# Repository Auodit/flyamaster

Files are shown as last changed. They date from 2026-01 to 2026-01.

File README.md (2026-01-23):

# 🚁 FLYAMASTER 飞控项目

> ⚠️ **版权警告 / COPYRIGHT WARNING** ⚠️
>
> **本项目受版权保护，严格保留所有权利！**
>
> 🚫 **禁止** 未经授权的复制、修改、分发、商用
> 🚫 **禁止** Fork、Clone、Download 本仓库
> 🚫 **禁止** 转载、引用本项目任何内容
>
> 违者将依法追究法律责任！详见 [LICENSE](LICENSE)
>
> ---
>
> **This project is protected by copyright. All rights strictly reserved!**
>
> 🚫 **PROHIBITED**: Unauthorized copying, modification, distribution, commercial use
> 🚫 **PROHIBITED**: Fork, Clone, Download this repository
> 🚫 **PROHIBITED**: Repost or cite any content from this project
>
> Violators will be prosecuted! See [LICENSE](LICENSE)

---

**项目名称**: FLYAMASTER - F405 Mini 高性能穿越机飞控
**版本**: v2.4.0
**最后更新**: 2026-01-23
**状态**: 🟢 开发中 (软件完成，硬件设计完成，等待验证)
**作者**: LI
**助手**: Doro *(Desktop Pet / 桌面宠物)*

---

## 📖 项目简介

FLYAMASTER 是一款基于 **STM32F405RGT6** 的高性能、开源、易扩展的四轴飞行控制器。

### 🌟 项目由来

> *"每个飞手心中都有一个造飞控的梦。"*

这个项目源于我对无人机的热爱。从第一次看到穿越机在空中翻滚、俯冲的那一刻起，我就被这种自由飞翔的感觉深深吸引。作为一名嵌入式开发者，我不满足于仅仅使用现成的飞控，而是想要**从零开始**，亲手打造一款属于自己的飞行控制器。

这不仅仅是一个技术项目，更是一段探索之旅——从最初的 Mahony 姿态解算调试，到 PID 参数的反复调优；从 DMA 通道冲突的抓狂，到最终看到四轴稳稳悬停的那一刻的成就感。每一行代码、每一条 PCB 走线，都凝聚着对飞行的热爱和对技术的追求。

**FLYAMASTER** = **FLY** (飞行) + **A** (一个) + **MASTER** (大师) —— 愿每一位使用者都能成为飞行大师！

### 🎯 多固件支持

本硬件设计兼容多种主流开源飞控固件：

| 固件 | 适用场景 | 支持状态 |
|---|---|---|
| **INAV** | 固定翼 / 长航时无人机 / GPS 导航 | ✅ 完全兼容 |
| **Betaflight** | 穿越机 / 竞速无人机 / 花飞 | ✅ 完全兼容 |
| **ArduPilot** | 专业航拍 / 测绘 / 自主任务 | ✅ 完全兼容 |
| **FLYAMASTER (自研)** | 学习研究 / 定制开发 | ✅ 原生支持 |

> 💡 **提示**: 硬件引脚分配遵循 Betaflight 标准，可直接使用 Betaflight Configurator 进行配置。
> 对于 INAV 和 ArduPilot，需要创建对应的 Target 定义文件。

### 核心特性

- **高性能 MCU**: STM32F405RGT6 (168MHz, 1MB Flash, 192KB RAM)
- **多固件兼容**: 支持 INAV / Betaflight / ArduPilot / 自研固件
- **宽电压输入**: 支持 **2S-9S 电池** (4.5V-40V)，兼容各类电调
- **板载 OSD**: AT7456E 视频叠加芯片，实时显示飞行数据
- **实时操作系统**: FreeRTOS CMSIS_V2 (自研固件)
- **姿态解算**: Mahony 互补滤波 (500Hz)
- **控制算法**: 串级 PID (角度环 + 角速度环)
- **传感器融合**: IMU + 气压计 + 磁力计 + GPS + 光流
- **遥控接收**: ELRS/CRSF 协议 (420kbps, 双向遥测)
- **黑匣子**: W25Q128 Flash 日志记录 (16MB)
- **状态指示**: 7 颗专业级 LED 飞行仪表盘
- **USB 反灌保护**: 肖特基二极管隔离，安全可靠

### 设计哲学

1. **控制回路隔离**: 姿态解算与 PID 控制拥有最高优先级
2. **DMA 满载策略**: 所有高吞吐量接口强制开启 DMA
3. **资源冲突零容忍**: 针对 F405 的 DMA 通道冲突采用硬件重映射方案

---

## 🧠 核心算法原理

### 姿态解算 - Mahony 互补滤波

飞控的"大脑"是姿态解算算法。我们采用 **Mahony 互补滤波器**，它巧妙地融合了陀螺仪和加速度计的数据：

```
                    ┌─────────────────────────────────────────┐
                    │         Mahony 互补滤波器               │
                    └─────────────────────────────────────────┘
                    
    陀螺仪 (高频响应)                      加速度计 (低频稳定)
         │                                      │
         ▼                                      ▼
    ┌─────────┐                           ┌─────────┐
    │ 角速度  │                           │ 重力向量│
    │ ω       │                           │ a       │
    └────┬────┘                           └────┬────┘
         │                                      │
         │    ┌──────────────────────────┐     │
         └───►│  四元数微分方程积分       │◄────┘
              │  q̇ = ½ q ⊗ ω_corrected   │
              └───────────┬──────────────┘
                          │
                          ▼
                    ┌─────────┐
                    │ 四元数 q │ ──► Roll, Pitch, Yaw
                    └─────────┘
```

**核心公式**:
- 误差估计: `e = a × v` (加速度计测量值与估计重力方向的叉积)
- PI 校正: `ω_corrected = ω_gyro + Kp·e + Ki·∫e·dt`
- 四元数更新: `q += ½·q⊗ω·dt`

### 串级 PID 控制

采用**角度环 + 角速度环**的串级结构，外环输出作为内环的设定值：

```
    目标角度 ──┬──► [角度环 PID] ──► 目标角速度 ──┬──► [角速度环 PID] ──► 电机输出
               │                                  │
    当前角度 ──┘                    当前角速度 ──┘
```

**为什么用串级？**
- 外环 (角度环): 响应慢但稳定，负责"往哪飞"
- 内环 (角速度环): 响应快，负责"怎么飞"
- 两环配合，既稳定又灵敏

### 电机混控 - Airmode 算法

X 型机架的混控公式：
```
M1 (右前) = Throttle - Roll - Pitch - Yaw
M2 (左后) = Throttle + Roll + Pitch - Yaw
M3 (左前) = Throttle + Roll - Pitch + Yaw
M4 (右后) = Throttle - Roll + Pitch + Yaw
```

**Airmode 的精髓**: 当电机输出超限时，整体平移油门中心，保证姿态控制差分不变——"姿态优先，油门让步"。

---

## ⚡ 电路设计亮点

### 宽电压电源架构 (2S-9S)

```
    电池 (4.5-40V) ──► SY8303 DCDC ──► 5V/3A ──► RT9193 LDO ──► 3.3V/500mA
         │                  │                         │
         │                  ├──► USB 5V (带反灌保护)   ├──► MCU
         │                  ├──► 蜂鸣器               ├──► 传感器
         │                  └──► 外设接口             └──► Flash/OSD
         │
         ├──► 电机 (直接电池供电)
         └──► ADC 电压检测 (1:11 分压)
```

**为什么选 SY8303？**
- 输入范围 4.5-40V，覆盖 2S-9S 电池
- 效率高达 95%，发热小
- SOT-23-6 封装，体积小巧
- 价格仅 ¥0.8，性价比极高

### USB 反灌保护

**问题**: 电池供电时，5V 会通过 USB 反灌到电脑，导致 MCU 误判 USB 已连接。

**解决方案**: 肖特基二极管 (SS14) 隔离 + PB9 检测引脚

```
    USB VBUS ──┬──[SS14 二极管]──► +5V_USB
               │
               └──[10kΩ]──► PB9 (USB_DETECT, Pull-down)
```

### 7 颗 LED 专业飞行仪表盘

| 分组 | LED | 颜色 | 功能 |
|:---|:---|:---|:---|
| 核心系统 | LED_SYS | 蓝 | 系统心跳 (闪烁=待机, 常亮=已解锁) |
| 核心系统 | LED_ERR | 红 | 警告/错误 (快闪=传感器故障) |
| 导航链路 | LED_GPS | 绿 | GPS 状态 (闪烁=搜星, 常亮=3D Fix) |
| 导航链路 | LED_RX | 黄 | 遥控信号 (常亮=正常, 灭=Failsafe) |
| 飞行任务 | LED_MODE | 白 | 飞行模式指示 |
| 飞行任务 | LED_LOG | 橙 | 黑匣子记录状态 |
| 飞行任务 | LED_VTX | 青 | 图传状态 |

---

## 🔧 问题发现与解决

开发过程中遇到了不少"坑"，这里记录一些典型问题和解决方案：

### 问题 1: DMA 通道冲突

**现象**: WS2812 RGB 灯和 SBUS 接收机同时工作时，数据错乱。

**原因**: STM32F4 的 DMA 通道是硬件绑定的，TIM3_CH4 和 UART4_RX 共用 DMA1_Stream2。

**解决**: 将 WS2812 从 TIM3_CH4 (PB1) 迁移到 TIM1_CH1 (PA8)，使用 DMA2 通道，彻底隔离。

### 问题 2: I2C 总线竞争

**现象**: 多任务环境下，MPU6050 和 SPL06 偶发读取失败。

**原因**: 两个任务同时访问 I2C1 总线，导致冲突。

**解决**: 引入 FreeRTOS 互斥锁 (`i2c1MutexHandle`)，所有 I2C 操作前加锁，操作后解锁。

### 问题 3: Failsafe 油门被覆盖 (严重!)

**现象**: 失控保护触发后，飞机不下降反而继续按遥控器油门飞行。

**原因**: 代码中先设置 `throttle = FAILSAFE_DESCENT_THROTTLE`，后又被 `throttle = SBUS_GetThrottle()` 覆盖。

**解决**: 在读取遥控器油门前检查 Failsafe 状态，Failsafe 期间跳过遥控器输入。

### 问题 4: 偏航角漂移

**现象**: 飞机静止时，Yaw 角缓慢漂移。

**原因**: 仅使用 6 轴 IMU (加速度计+陀螺仪)，无法校正偏航。

**解决**: 集成 QMC5883L 磁力计，升级为 9 轴 AHRS，利用地磁场校正偏航。

### 问题 5: 高频 printf 导致控制抖动

**现象**: 在 500Hz 的 IMU 任务中加 printf 调试，飞机开始抖动。

**原因**: printf 是阻塞式的，每次调用耗时 1-2ms，严重影响控制回路。

**解决**: 开发 RingBuffer 异步日志系统，`Log_Printf()` 仅需 <10us，数据通过 DMA 后台发送。

---

## 🛠️ 技术栈

| 类别 | 技术选型 | 说明 |
|---|---|---|
| **MCU** | STM32F405RGT6 | ARM Cortex-M4F @ 168MHz |
| **RTOS** | FreeRTOS | CMSIS_V2 接口 |
| **IDE** | Keil MDK-ARM | ARM Compiler 6 |
| **配置工具** | STM32CubeMX | HAL 库生成 |
| **EDA** | KiCad 9.0 | PCB 设计 |
| **调试** | 匿名上位机 V7 | 实时数据可视化 |

---

## 📐 硬件设计

### PCB 渲染图

| 正面 (Top) | 反面 (Bottom) |
|:---:|:---:|
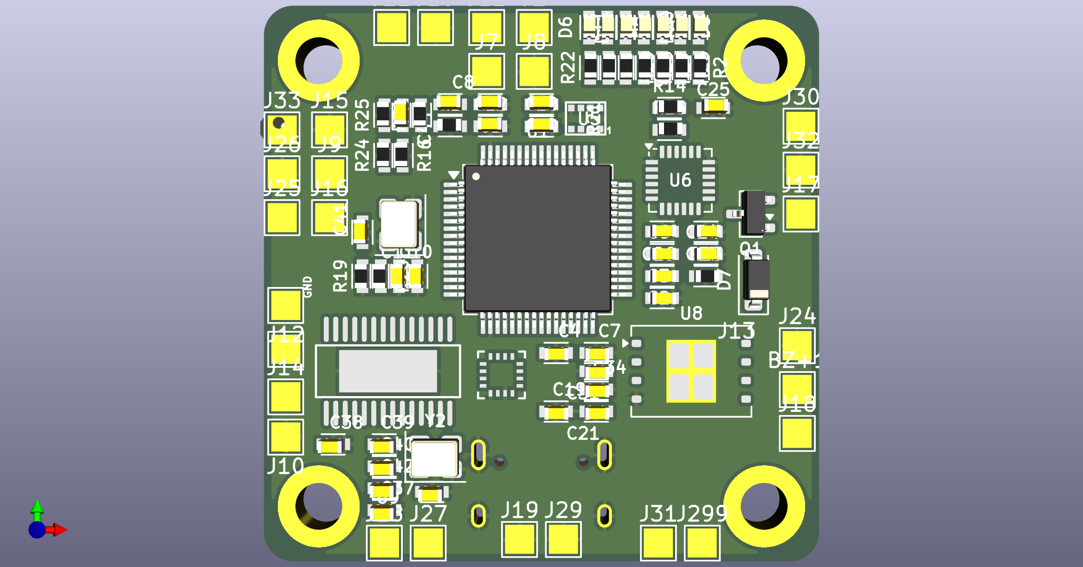
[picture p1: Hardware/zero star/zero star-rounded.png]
PCB 正面
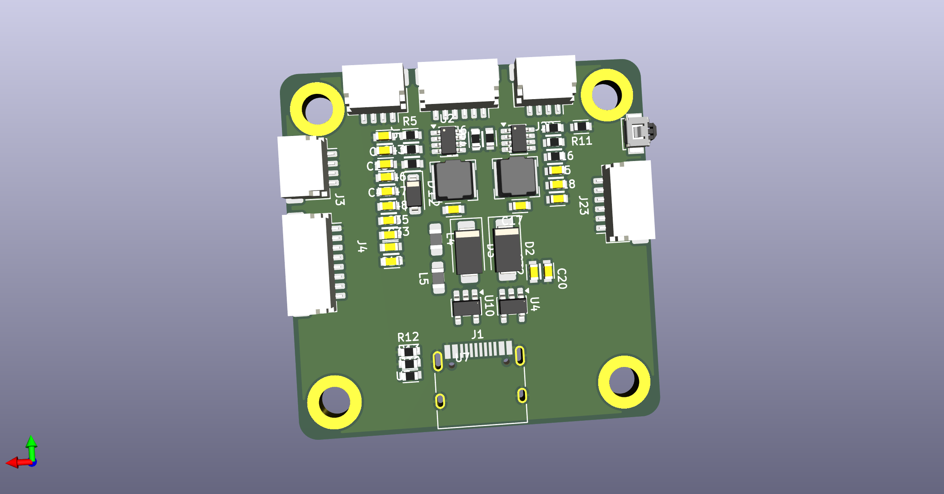
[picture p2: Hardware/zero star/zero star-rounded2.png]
PCB 反面
|  |  |

### 原理图

📄 **原理图 PDF**: [Hardware/zero star/zero star.pdf](Hardware/zero%20star/zero%20star.pdf)

### 主要芯片

| 芯片 | 功能 | 接口 |
|---|---|---|
| STM32F405RGT6 | 主控 MCU | - |
| MPU6050 | 6轴 IMU | I2C1 (0x68) |
| SPL06-001 | 气压计 | I2C1 (0x76) |
| QMC5883L | 磁力计 | I2C1 (0x0D) |
| W25Q128 | 16MB Flash | SPI1 |
| AT7456E | OSD 视频叠加 | SPI1 |
| SY8303 | DCDC 5V/3A (2S-9S 输入) | - |
| RT9193-33 | LDO 3.3V/500mA | - |

### 接口定义

| 接口 | 引脚 | 功能 | 波特率 |
|---|---|---|---|
| J1 | USB-C | 固件升级/调参 | CDC |
| J2 | PA2/PA3 | GPS 模块 | 115200 |
| J3 | PA9/PA10 | K210 上位机 | 921600 |
| J4 | PC6-PC9 | 4-in-1 ESC | PWM 400Hz |
| J5 | PC12/PD2 | 光流模块 | 115200 |
| J6 | PC10/PC11 | VTX SmartAudio | 115200  |
| J22 | PB10/PB11 | ELRS 接收机 | 420000 (CRSF) |

---

## 📚 文档索引

| 编号 | 文档名称 | 说明 | 链接 |
|---|---|---|---|
| 00 | README.md | 项目总览与索引 (本文档) | - |
| 01 | 01_definitions.md | 命名规范与接口定义 | [查看](plans/01_definitions.md) |
| 02 | 02_project_roadmap.md | 项目路线图与待办事项 | [查看](plans/02_project_roadmap.md) |
| 03 | 03_issue_tracker.md | 问题追踪日志 (Bug/Risk) | [查看](plans/03_issue_tracker.md) |
| 04 | 04_algo_design.md | 算法设计与优化记录 | [查看](plans/04_algo_design.md) |
| 05 | 05_changelog.md | 版本更新日志 | [查看](plans/05_changelog.md) |
| 06 | 06_operation_guide.md | 操作指南与环境搭建 | [查看](plans/06_operation_guide.md) |
| 07 | 07_research_and_ideas.md | 调研分析与创意池 | [查看](plans/07_research_and_ideas.md) |
| 08 | 08_hardware_design.md | 硬件架构与 PCB 设计 | [查看](plans/08_hardware_design.md) |

---

## 🚀 快速开始

### 1. 环境准备

```bash
# 必需软件
- Keil MDK-ARM v5.38+
- STM32CubeMX v6.10+
- ST-Link 驱动
```

### 2. 编译项目

1. 打开 `FLYAMASTER/MDK-ARM/FLYAMASTER.uvprojx`
2. 点击 `Build` (F7) 编译
3. 点击 `Download` (F8) 烧录

### 3. 调试连接

- **SWD 接口**: PA13 (SWDIO), PA14 (SWCLK)
- **USB 虚拟串口**: PA11/PA12 (CDC)
- **匿名上位机**: USART1 (PA9/PA10) @ 921600 baud

---

## 📁 目录结构

```
FLYAMASTER/
├── 3D/                      # 3D 模型文件
├── FLYAMASTER/              # 固件源代码
│   ├── Core/
│   │   ├── Inc/             # 头文件
│   │   │   ├── mpu6050.h    # IMU 驱动
│   │   │   ├── mahony.h     # 姿态解算
│   │   │   ├── pid.h        # PID 控制器
│   │   │   ├── motor.h      # 电机混控
│   │   │   ├── sbus.h       # CRSF 接收
│   │   │   ├── gps.h        # GPS 解析
│   │   │   ├── at7456e.h    # OSD 驱动
│   │   │   └── ...
│   │   └── Src/             # 源文件
│   │       ├── freertos.c   # RTOS 任务
│   │       ├── mpu6050.c    # IMU 驱动实现
│   │       ├── mahony.c     # Mahony 滤波
│   │       ├── pid.c        # PID 算法
│   │       ├── motor.c      # 电机控制
│   │       └── ...
│   └── MDK-ARM/             # Keil 工程
│       ├── FLYAMASTER.uvprojx
│       └── ...
├── Hardware/                # 硬件设计
│   └── zero star/           # KiCad 工程
│       ├── zero star.kicad_sch    # 原理图
│       ├── zero star.kicad_pcb    # PCB
│       └── zero star.pdf          # 原理图 PDF
├── plans/                   # 项目文档
│   ├── README.md            # 文档索引
│   ├── 01_definitions.md    # 接口定义
│   ├── 02_project_roadmap.md # 路线图
│   ├── 03_issue_tracker.md  # 问题追踪
│   ├── 04_algo_design.md    # 算法设计
│   ├── 05_changelog.md      # 更新日志
│   ├── 06_operation_guide.md # 操作指南
│   ├── 07_research_and_ideas.md # 调研分析
│   ├── 08_hardware_design.md # 硬件设计
│   └── archive/             # 废弃文档归档
├── .gitignore               # Git 忽略规则
└── LICENSE                  # 版权声明
```

---

## 🎯 项目状态

### ✅ 已完成

- [x] 硬件驱动 (IMU, PWM, CRSF, GPS, OSD)
- [x] 姿态解算 (Mahony 互补滤波)
- [x] 姿态控制 (串级 PID)
- [x] 定高控制 (气压计 PID)
- [x] GPS 定点 (位置环 PID)
- [x] OSD 显示 (AT7456E)
- [x] 匿名上位机协议 (V7)
- [x] 硬件原理图设计 (KiCad)
- [x] 7 颗 LED 状态指示系统
- [x] USB 插入检测 (反灌保护)

### 🚧 进行中

- [ ] PCB 布局优化
- [ ] 打样验证

### 📋 计划中

- [ ] EKF 状态估计 (可选)
- [ ] 航点飞行
- [ ] 自动返航 (RTH)

---

## 👥 贡献者

- **LI** - 项目作者 & 核心开发者
- **Doro** *(Desktop Pet / 桌面宠物)* - AI 助手 & 文档撰写

---

## ⚖️ 版权声明

```
================================================================================
                    FLYAMASTER 飞控项目 - 版权声明
================================================================================

版权所有 (C) 2026 FLYAMASTER 项目组
Copyright (C) 2026 FLYAMASTER Project Team

                       严格保留所有权利
                  ALL RIGHTS STRICTLY RESERVED

未经版权所有者明确书面授权，严禁：
1. 复制、下载、存储本项目的任何部分
2. 修改、改编、翻译本项目的任何内容
3. 分发、传播、共享本项目的任何文件
4. 将本项目用于任何商业目的
5. 基于本项目创建衍生作品
6. 对本项目进行逆向工程
7. 在任何平台转载、引用本项目内容

任何未经授权的使用将被视为侵权，版权所有者保留追究法律责任的权利。

详见 LICENSE 文件
================================================================================
```

---

## 🙏 致谢

感谢开源社区的前辈们，特别是：
- **Betaflight** / **INAV** / **ArduPilot** 项目，提供了宝贵的参考
- **Mahony** 和 **Madgwick** 的姿态解算算法论文
- **立创开源硬件平台**，提供了电源方案参考
- 所有在 GitHub Issues 中提供反馈的朋友们

---

**文档版本**: v2.4.0
**最后更新**: 2026-01-23
**作者**: LI | **助手**: Doro

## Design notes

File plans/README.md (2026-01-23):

# 🚁 FLYAMASTER 飞控项目

> ⚠️ **版权警告 / COPYRIGHT WARNING** ⚠️
>
> **本项目受版权保护，严格保留所有权利！**
>
> 🚫 **禁止** 未经授权的复制、修改、分发、商用
> 🚫 **禁止** Fork、Clone、Download 本仓库
> 🚫 **禁止** 转载、引用本项目任何内容
>
> 违者将依法追究法律责任！详见 [LICENSE](../LICENSE)
>
> ---
>
> **This project is protected by copyright. All rights strictly reserved!**
>
> 🚫 **PROHIBITED**: Unauthorized copying, modification, distribution, commercial use
> 🚫 **PROHIBITED**: Fork, Clone, Download this repository
> 🚫 **PROHIBITED**: Repost or cite any content from this project
>
> Violators will be prosecuted! See [LICENSE](../LICENSE)

---

**项目名称**: FLYAMASTER - F405 Mini 高性能穿越机飞控
**版本**: v2.4.0
**最后更新**: 2026-01-23
**状态**: 🟢 开发中 (软件完成，硬件设计完成，等待验证)

---

## 📖 项目简介

FLYAMASTER 是一款基于 **STM32F405RGT6** 的高性能、开源、易扩展的四轴飞行控制器。

### 核心特性

- **高性能 MCU**: STM32F405RGT6 (168MHz, 1MB Flash, 192KB RAM)
- **实时操作系统**: FreeRTOS CMSIS_V2
- **姿态解算**: Mahony 互补滤波 (500Hz)
- **控制算法**: 串级 PID (角度环 + 角速度环)
- **传感器融合**: IMU + 气压计 + 磁力计 + GPS + 光流
- **OSD 显示**: AT7456E 视频叠加
- **黑匣子**: W25Q128 Flash 日志记录

### 设计哲学

1. **控制回路隔离**: 姿态解算与 PID 控制拥有最高优先级
2. **DMA 满载策略**: 所有高吞吐量接口强制开启 DMA
3. **资源冲突零容忍**: 针对 F405 的 DMA 通道冲突采用硬件重映射方案

---

## 🛠️ 技术栈

| 类别 | 技术选型 | 说明 |
|---|---|---|
| **MCU** | STM32F405RGT6 | ARM Cortex-M4F @ 168MHz |
| **RTOS** | FreeRTOS | CMSIS_V2 接口 |
| **IDE** | Keil MDK-ARM | ARM Compiler 6 |
| **配置工具** | STM32CubeMX | HAL 库生成 |
| **EDA** | 立创 EDA / KiCad | PCB 设计 |
| **调试** | 匿名上位机 V7 | 实时数据可视化 |

---

## 📚 文档索引

| 编号 | 文档名称 | 说明 | 链接 |
|---|---|---|---|
| 00 | README.md | 项目总览与索引 (本文档) | - |
| 01 | 01_definitions.md | 命名规范与接口定义 | [查看](01_definitions.md) |
| 02 | 02_project_roadmap.md | 项目路线图与待办事项 | [查看](02_project_roadmap.md) |
| 03 | 03_issue_tracker.md | 问题追踪日志 (Bug/Risk) | [查看](03_issue_tracker.md) |
| 04 | 04_algo_design.md | 算法设计与优化记录 | [查看](04_algo_design.md) |
| 05 | 05_changelog.md | 版本更新日志 | [查看](05_changelog.md) |
| 06 | 06_operation_guide.md | 操作指南与环境搭建 | [查看](06_operation_guide.md) |
| 07 | 07_research_and_ideas.md | 调研分析与创意池 | [查看](07_research_and_ideas.md) |
| 08 | 08_hardware_design.md | 硬件架构与 PCB 设计 | [查看](08_hardware_design.md) |

---

## 🚀 快速开始

### 1. 环境准备

```bash
# 必需软件
- Keil MDK-ARM v5.38+
- STM32CubeMX v6.10+
- ST-Link 驱动
```

### 2. 编译项目

1. 打开 `MDK-ARM/FLYAMASTER.uvprojx`
2. 点击 `Build` (F7) 编译
3. 点击 `Download` (F8) 烧录

### 3. 调试连接

- **SWD 接口**: PA13 (SWDIO), PA14 (SWCLK)
- **USB 虚拟串口**: PA11/PA12 (CDC)
- **匿名上位机**: UART5 (PC12/PD2) @ 115200 baud

---

## 📁 目录结构

```
FLYAMASTER/
├── Core/
│   ├── Inc/                 # 头文件
│   │   ├── mpu6050.h        # IMU 驱动
│   │   ├── mahony.h         # 姿态解算
│   │   ├── pid.h            # PID 控制器
│   │   ├── motor.h          # 电机混控
│   │   ├── sbus.h           # 遥控器接收
│   │   ├── gps.h            # GPS 解析
│   │   ├── at7456e.h        # OSD 驱动
│   │   └── ...
│   └── Src/                 # 源文件
│       ├── freertos.c       # RTOS 任务
│       ├── mpu6050.c        # IMU 驱动实现
│       ├── mahony.c         # Mahony 滤波
│       ├── pid.c            # PID 算法
│       ├── motor.c          # 电机控制
│       └── ...
├── MDK-ARM/                 # Keil 工程
│   ├── FLYAMASTER.uvprojx   # 工程文件
│   └── ...
└── plans/                   # 项目文档
    ├── README.md            # 本文档
    ├── 01_definitions.md    # 接口定义
    ├── 02_project_roadmap.md # 路线图
    ├── 03_issue_tracker.md  # 问题追踪
    ├── 04_algo_design.md    # 算法设计
    ├── 05_changelog.md      # 更新日志
    ├── 06_operation_guide.md # 操作指南
    ├── 07_research_and_ideas.md # 调研分析
    ├── 08_hardware_design.md # 硬件设计
    └── archive/             # 废弃文档归档
```

---

## 🎯 项目状态

### ✅ 已完成

- [x] 硬件驱动 (IMU, PWM, SBUS, GPS, OSD)
- [x] 姿态解算 (Mahony 互补滤波)
- [x] 姿态控制 (串级 PID)
- [x] 定高控制 (气压计 PID)
- [x] GPS 定点 (位置环 PID)
- [x] OSD 显示 (AT7456E)
- [x] 匿名上位机协议 (V7)

### 🚧 进行中

- [ ] 硬件原理图设计
- [ ] PCB 布局
- [ ] 打样验证

### 📋 计划中

- [ ] EKF 状态估计 (可选)
- [ ] 航点飞行
- [ ] 自动返航 (RTH)

---

## 👥 贡献者

- **Q版 Doro** - 项目负责人
- **Kilo Code** - AI 辅助开发

---

## ⚖️ 版权声明

```
================================================================================
                    FLYAMASTER 飞控项目 - 版权声明
================================================================================

版权所有 (C) 2026 FLYAMASTER 项目组
Copyright (C) 2026 FLYAMASTER Project Team

                       严格保留所有权利
                  ALL RIGHTS STRICTLY RESERVED

未经版权所有者明确书面授权，严禁：
1. 复制、下载、存储本项目的任何部分
2. 修改、改编、翻译本项目的任何内容
3. 分发、传播、共享本项目的任何文件
4. 将本项目用于任何商业目的
5. 基于本项目创建衍生作品
6. 对本项目进行逆向工程
7. 在任何平台转载、引用本项目内容

任何未经授权的使用将被视为侵权，版权所有者保留追究法律责任的权利。

详见 LICENSE 文件
================================================================================
```

---

**文档版本**: v2.4.0
**最后更新**: 2026-01-23

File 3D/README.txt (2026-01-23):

Peon230 - Quadcopter by Tech2C on Thingiverse: https://www.thingiverse.com/thing:629338

Summary:
Designed for strength, function and light weight, build yourself this 230 size Quadcopter frame.  All parts printed at 0.2mm layer height and 3 perimeters.  -Top and Bottom frames, HDcam and FPVcam @ 30% infill x 1 of each-Arms @ 100% infill x 4-ArmSupport @ 100% infill x 2 http://youtu.be/-e-3kbXzwzkhttp://youtu.be/jaZK9bDb17Uhttp://youtu.be/BU2Z-EG56js  Suggested Setup:-Motor: RacerStar 1806 2280kv or Racerstar 2204 2300KV-ESC: Racerstar RS20Ax4 20A 4 in 1 (inbuilt PDB)-Prop: 10 Pairs GEPRC 5040 V2 5 Inch 3 Blade Propeller -Flight Controller: F3 Acro or F4 with Current Sensor-Battery: ZOP 3S 1100mah 65c or ZOP 4S 1100mah 65c-LiPo Battery Charger:iMAX B6 Digital RC Lipo Balance Charger12V 5A AC Power AdapterXT60 Connector to Banana Plug-Remote Control:FlySky FS-i6 orFrSky Taranis Transmitter and FrSky XM+ ReceiverHDcam mounting strap slots compatible with Mobius, RunCam and GoPro. -Optional extras if you need them:Lipo Battery Tie Down StrapXT60 Male Female Plug Connector 12AWG 10cm Power CableSilicone Anti-vibration Pad in for 22XX Series MotorNon-printed parts required:-12 x M3x10mm countersunk screws for Top/Bottom frame (Amazon affiliate link)-6 x M3x40mm Nylon Spacers for Top/Bottom frame (Amazon affiliate link)-8 x M3x12mm countersunk screws for Arms (Amazon affiliate link)-8 x M3 Nyloc nuts for Arms (Amazon affiliate link)-3 x Vibration Ball Dampeners for HDcamUpdatedBase and Top v1.1 - rear mounting spacers moved further back for better rear arm support.Added 22 size Motor ArmEnjoy this design? Consider supporting me on Patreon: https://www.patreon.com/Tech2C

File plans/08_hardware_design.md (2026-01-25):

# 🛠️ 硬件架构与PCB设计 (Hardware Design)

**版本**: v2.5.7 (STM32F405RGT6 - PCB Layout Final)
**最后更新**: 2026-01-25
**状态**: ✅ CubeMX 已生成

---

## 0. 硬件变更记录 (Hardware Revision Log)

| 版本 | 日期 | 变更内容 |
|:---|:---|:---|
| v2.0.0 | 2026-01-18 | 迁移至 STM32F405RGT6 (LQFP-64) |
| v2.2.0 | 2026-01-23 | 串口重新分配：USART3 用于 ELRS |
| v2.3.0 | 2026-01-23 | 新增 7 颗 LED |
| v2.4.0 | 2026-01-23 | 新增 USB 插入检测 (PB9) |
| v2.5.0 | 2026-01-24 | PCB 布局深度优化：按物理边沿重排引脚 |
| v2.5.2 | 2026-01-24 | 布局微调：顶部仅保留传感器，插座全部移至左/右/下侧 |
| v2.5.3 | 2026-01-24 | USART2/UART5 对调：UART5 用于 GPS，USART2 用于光流 |
| v2.5.4 | 2026-01-24 | 引脚调整：PC5 改为 USB_DETECT，电流检测移至 PC1 (ADC11) |
| v2.5.5 | 2026-01-24 | I2C1_SCL 重映射：PB6 → PB8 |
| v2.5.6 | 2026-01-24 | I2C1 完整重映射 (PB8/PB9)，USART1 重映射 (PB6/PB7) |
| **v2.5.7** | **2026-01-25** | **SPI 片选对调：PA4→OSD_CS，PC4→FLASH_CS** |

---

## 1. MCU 引脚分配表 (Pinout Map) - 按物理边沿排列

> **方向定义**: 以芯片丝印正向为准，Pin 1 为左上角。

### 1.1 顶部边沿 (Top Edge, Pins 49-64)
*布局目标: I2C 传感器 (PCB 顶部区域)*

| Pin | Label | Function | Net Name | Note |
|:---|:---|:---|:---|:---|
| PB9 | I2C1_SDA | I2C1 | I2C1_SDA | **传感器总线** (重映射) |
| PB8 | I2C1_SCL | I2C1 | I2C1_SCL | **传感器总线** (重映射) |
| BOOT0 | BOOT0 | System | BOOT0 | 启动模式选择 (背面开关) |
| PB7 | USART1_RX | USART1 | VTX_RX | **SmartAudio 图传** (重映射) |
| PB6 | USART1_TX | USART1 | VTX_TX | **SmartAudio 图传** (重映射) |
| PB5 | MPU_INT | GPIO_EXTI5 | MPU_INT | IMU 中断 |
| PB4 | GPIO_Output | GPIO_Output | - | 备用 |
| PB3 | GPIO_Output | GPIO_Output | - | 备用 |
| PD2 | UART5_RX | UART5 | **GPS_RX** | **GPS 模块** (引至左侧插座) |
| PC12 | UART5_TX | UART5 | **GPS_TX** | **GPS 模块** (引至左侧插座) |
| PC11 | UART4_RX | UART4 | LOG_RX | K210/调试日志 (引至左侧插座) |
| PC10 | UART4_TX | UART4 | LOG_TX | K210/调试日志 (引至左侧插座) |
| PA15 | - | - | - | 备用 |
| PA14 | SWCLK | SYS | SWCLK | SWD 调试接口 |

### 1.2 右侧边沿 (Right Edge, Pins 33-48)
*布局目标: USB, VTX, Motors, LEDs*

| Pin | Label | Function | Net Name | Note |
|:---|:---|:---|:---|:---|
| PA13 | SWDIO | SYS | SWDIO | SWD 调试接口 |
| PA12 | USB_DP | USB_OTG_FS | USB_DP | USB Type-C (背面) |
| PA11 | USB_DM | USB_OTG_FS | USB_DM | USB Type-C (背面) |
| PA10 | GPIO_Output | GPIO_Output | - | 备用 (原 USART1_RX) |
| PA9 | GPIO_Output | GPIO_Output | - | 备用 (原 USART1_TX) |
| PA8 | LED_RGB | TIM1_CH1 | LED_RGB | 4颗 WS2812 (位于PCB四角) |
| PC9 | MOTOR_4 | TIM8_CH4 | M4 | 电机 4 (CW) |
| PC8 | MOTOR_3 | TIM8_CH3 | M3 | 电机 3 (CCW) |
| PC7 | MOTOR_2 | TIM8_CH2 | M2 | 电机 2 (CCW) |
| PC6 | MOTOR_1 | TIM8_CH1 | M1 | 电机 1 (CW) |
| PB15 | LED_VTX | GPIO_Output | LED_VTX | 状态灯 4 (青色) - 图传 |
| PB14 | LED_LOG | GPIO_Output | LED_LOG | 状态灯 3 (橙色) - 日志 |
| PB13 | LED_MODE | GPIO_Output | LED_MODE | 状态灯 2 (白色) - 模式 |
| PB12 | LED_SYS | GPIO_Output | LED_SYS | 状态灯 1 (蓝色) - 系统 |

### 1.3 底部边沿 (Bottom Edge, Pins 17-32)
*布局目标: SPI (Flash/OSD), ELRS, 光流*

| Pin | Label | Function | Net Name | Note |
|:---|:---|:---|:---|:---|
| PB11 | USART3_RX | USART3 | ELRS_RX | **ELRS 接收机** (焊盘) |
| PB10 | USART3_TX | USART3 | ELRS_TX | **ELRS 接收机** (焊盘) |
| PB2 | GPIO_Output | GPIO_Output | - | 备用 (BOOT1) |
| PB1 | GPIO_Output | GPIO_Output | - | 备用 |
| PB0 | GPIO_Output | GPIO_Output | - | 备用 |
| PC5 | USB_DETECT | GPIO_Input | USB_DET | **USB 插入检测** |
| PC4 | FLASH_CS | GPIO_Output | FLASH_CS | **Flash 片选** (靠近 SPI) |
| PA7 | SPI1_MOSI | SPI1 | SPI1_MOSI | Flash + OSD |
| PA6 | SPI1_MISO | SPI1 | SPI1_MISO | Flash + OSD |
| PA5 | SPI1_SCK | SPI1 | SPI1_SCK | Flash + OSD |
| PA4 | OSD_CS | GPIO_Output | OSD_CS | **OSD 片选** |
| PA3 | USART2_RX | USART2 | **FLOW_RX** | **光流模块** (底部/左侧插座) |

### 1.4 左侧边沿 (Left Edge, Pins 1-16)
*布局目标: Power, Buzzer, 光流*

| Pin | Label | Function | Net Name | Note |
|:---|:---|:---|:---|:---|
| PA2 | USART2_TX | USART2 | **FLOW_TX** | **光流模块** (底部/左侧插座) |
| PA1 | - | - | - | 备用 |
| PA0 | Power_Key | GPIO_Input | POWER_KEY | 电源按键 (可选) |
| PC3 | - | - | - | 备用 |
| PC2 | BUZZER | GPIO_Output | BUZZER | 蜂鸣器 |
| PC1 | I_BAT | ADC1_IN11 | CURR_SENSE | **电流检测** |
| PC0 | V_BAT | ADC1_IN10 | VBAT_SENSE | 电压检测 |
| NRST | NRST | System | NRST | 复位 |
| PH1 | OSC_OUT | RCC | HSE_OUT | 8MHz 晶振 |
| PH0 | OSC_IN | RCC | HSE_IN | 8MHz 晶振 |

---

## 2. 串口分配汇总 (UART Assignment Summary)

| 串口 | 引脚 | 波特率 | 用途 | 接口类型 | 位置 |
|:---|:---|:---|:---|:---|:---|
| **USART1** | PB6/PB7 | 4800 | SmartAudio VTX | J6 插座 | 顶部 (重映射) |
| **USART2** | PA2/PA3 | 115200 | **光流模块** | J5 插座 | 底部/左侧 |
| **USART3** | PB10/PB11 | 420000 | ELRS (CRSF) | 焊盘 | 底部 |
| **UART4** | PC10/PC11 | 921600 | K210/日志 | J3 插座 | 顶部→左侧 |
| **UART5** | PC12/PD2 | 115200 | **GPS 模块** | J2 插座 | 顶部→左侧 |

---

## 3. 关键布局约束 (PCB Layout Constraints)

### 3.1 物理分区
*   **Top (上)**: **传感器专用区**。MPU6050, SPL06, QMC5883L 放置在 PCB 顶部中间，I2C 走线极短。**顶部边缘不放置任何插座**。
*   **Right (右)**: **接口区**。USB Type-C (背面), J6 (VTX), 电机焊盘。
*   **Bottom (下)**: **存储与 OSD 区**。Flash, AT7456E, ELRS 焊盘。SPI 走线紧凑。
*   **Left (左)**: **电源与外设区**。LDO, DCDC, ADC 检测。GPS (J2), 光流 (J5), 日志 (J3) 插座。

### 3.2 特殊走线要求
*   **USB (PA11/PA12)**: 差分走线，90Ω 阻抗控制，尽量短。
*   **OSD 视频线**: 模拟视频信号 (VIN/VOUT) 必须包地，远离 DCDC 电感和电机线。
*   **晶振 (PH0/PH1)**: 下方挖空，禁止走线，包地保护。
*   **电流检测 (PC5)**: 采样电阻出来的信号线需开尔文连接 (Kelvin Connection)。

---

## 4. LED 指示灯系统 (4 颗)

| 引脚 | 颜色 | 标签 | 功能定义 | 状态逻辑 (低电平亮) |
|:---|:---|:---|:---|:---|
| **PB12** | **蓝色** | **LED_SYS** | **系统状态** | **闪烁**: 待机正常 (心跳)<br>**常亮**: 已解锁 (Armed)<br>**灭**: 初始化中 |
| **PB13** | **白色** | **LED_MODE** | **飞行模式** | **灭**: 自稳/半自稳 (Angle/Horizon)<br>**亮**: 手动模式 (Acro)<br>**闪烁**: 返航/救援 (RTH/Rescue) |
| **PB14** | **绿色** | **LED_GPS** | **GPS 状态** | **灭**: 无 GPS 信号<br>**闪烁**: 搜星中<br>**常亮**: GPS 3D 锁定 (Ready) |
| **PB15** | **青色** | **LED_VTX** | **图传/警告** | **灭**: 正常<br>**亮**: 图传处于 PIT 模式 (低功率)<br>**快闪**: 电池低压/故障警告 |

---

## 5. DMA 通道分配

由于串口位置变更，DMA 通道需重新确认：

*   **USART1 (VTX)**: PB6/PB7 (重映射). DMA2_Stream7 (TX) / DMA2_Stream2 (RX). **OK**.
*   **USART2 (光流)**: PA2/PA3. DMA1_Stream6 (TX) / DMA1_Stream5 (RX). **OK**.
*   **USART3 (ELRS)**: PB10/PB11. DMA1_Stream3 (TX) / DMA1_Stream1 (RX). **OK**.
*   **UART4 (Log)**: PC10/PC11. DMA1_Stream4 (TX) / DMA1_Stream2 (RX). **OK**.
*   **UART5 (GPS)**: PC12/PD2. DMA1_Stream7 (TX) / DMA1_Stream0 (RX). **OK**.

---

## 6. 备用引脚汇总

| 引脚 | 位置 | 可用功能 | 建议用途 |
|:---|:---|:---|:---|
| PC13 | 左上 | GPIO (RTC 备份域) | 备用 LED 或使能信号 |
| PC14 | 左上 | GPIO (LSE) | 备用 (需禁用 LSE) |
| PC15 | 左上 | GPIO (LSE) | 备用 (需禁用 LSE) |
| PA0 | 左下 | GPIO/ADC | Power_Key 或备用 ADC |
| PA1 | 左下 | GPIO/ADC | 备用 ADC |
| PA9/PA10 | 右侧 | GPIO/USART1 | 备用 (原 USART1) |
| PA15 | 右上 | GPIO/TIM2_CH1 | 备用 PWM 或 GPIO |
| PB0/PB1/PB2 | 底部 | GPIO/ADC | 备用 |
| PB3/PB4 | 顶部 | GPIO/SPI3 | 备用 |
| PC3 | 左侧 | GPIO/ADC | 备用 |

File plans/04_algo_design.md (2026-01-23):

# 算法设计与优化记录

> 文档版本: 1.0.0  
> 更新日期: 2026-01-18  
> 项目: FLYAMASTER 四轴飞控

---

## 目录

1. [姿态解算算法 (Mahony Filter)](#1-姿态解算算法-mahony-filter)
2. [串级 PID 控制器](#2-串级-pid-控制器)
3. [电机混控算法](#3-电机混控算法)
4. [气压高度计算](#4-气压高度计算)
5. [快速数学函数](#5-快速数学函数)
6. [滤波算法](#6-滤波算法)

---

## 1. 姿态解算算法 (Mahony Filter)

### 1.1 算法概述

Mahony 互补滤波器是一种基于四元数的姿态估计算法，通过融合陀螺仪和加速度计数据，实现高精度、低延迟的姿态解算。

**文件位置**: [`mahony.c`](../FLYAMASTER/Core/Src/mahony.c), [`mahony.h`](../FLYAMASTER/Core/Inc/mahony.h)

### 1.2 数学原理

#### 四元数表示

姿态使用四元数 $\mathbf{q} = [q_0, q_1, q_2, q_3]^T$ 表示，其中：
- $q_0$ 为标量部分 (w)
- $q_1, q_2, q_3$ 为向量部分 (x, y, z)

约束条件：$\|\mathbf{q}\| = 1$

#### 四元数微分方程

$$\dot{\mathbf{q}} = \frac{1}{2} \mathbf{q} \otimes \boldsymbol{\omega}$$

其中 $\boldsymbol{\omega} = [0, \omega_x, \omega_y, \omega_z]^T$ 为角速度四元数。

展开形式：
$$\begin{bmatrix} \dot{q}_0 \\ \dot{q}_1 \\ \dot{q}_2 \\ \dot{q}_3 \end{bmatrix} = \frac{1}{2} \begin{bmatrix} -q_1 & -q_2 & -q_3 \\ q_0 & -q_3 & q_2 \\ q_3 & q_0 & -q_1 \\ -q_2 & q_1 & q_0 \end{bmatrix} \begin{bmatrix} \omega_x \\ \omega_y \\ \omega_z \end{bmatrix}$$

#### 误差估计

利用加速度计测量的重力方向与四元数估计的重力方向之间的误差：

估计的重力方向（从四元数计算）：
$$\mathbf{v} = \begin{bmatrix} 2(q_1 q_3 - q_0 q_2) \\ 2(q_0 q_1 + q_2 q_3) \\ q_0^2 - q_1^2 - q_2^2 + q_3^2 \end{bmatrix}$$

误差向量（叉积）：
$$\mathbf{e} = \mathbf{a} \times \mathbf{v}$$

其中 $\mathbf{a}$ 为归一化的加速度计测量值。

#### PI 校正

使用 PI 控制器校正陀螺仪漂移：

$$\boldsymbol{\omega}_{corrected} = \boldsymbol{\omega}_{gyro} + K_p \mathbf{e} + K_i \int \mathbf{e} \, dt$$

### 1.3 伪代码

```
function Mahony_UpdateIMU(gx, gy, gz, ax, ay, az):
    dt = 1 / sample_freq
    
    // 归一化加速度计
    norm = sqrt(ax² + ay² + az²)
    ax, ay, az = ax/norm, ay/norm, az/norm
    
    // 估计重力方向
    vx = q1*q3 - q0*q2
    vy = q0*q1 + q2*q3
    vz = q0² - 0.5 + q3²
    
    // 计算误差 (叉积)
    ex = ay*vz - az*vy
    ey = az*vx - ax*vz
    ez = ax*vy - ay*vx
    
    // 积分误差
    integralFBx += Ki * ex * dt
    integralFBy += Ki * ey * dt
    integralFBz += Ki * ez * dt
    
    // 校正角速度
    gx += Kp * ex + integralFBx
    gy += Kp * ey + integralFBy
    gz += Kp * ez + integralFBz
    
    // 积分四元数
    gx *= 0.5 * dt
    gy *= 0.5 * dt
    gz *= 0.5 * dt
    
    q0 += -q1*gx - q2*gy - q3*gz
    q1 += q0*gx + q2*gz - q3*gy
    q2 += q0*gy - q1*gz + q3*gx
    q3 += q0*gz + q1*gy - q2*gx
    
    // 归一化四元数
    normalize(q0, q1, q2, q3)
```

### 1.4 四元数转欧拉角

$$\phi = \arctan2(2(q_0 q_1 + q_2 q_3), 1 - 2(q_1^2 + q_2^2))$$

$$\theta = \arcsin(2(q_0 q_2 - q_3 q_1))$$

$$\psi = \arctan2(2(q_0 q_3 + q_1 q_2), 1 - 2(q_2^2 + q_3^2))$$

### 1.5 参数配置

| 参数 | 默认值 | 说明 |
|---|---|---|
| `MAHONY_DEFAULT_KP` | 2.0 | 比例增益，越大收敛越快但可能振荡 |
| `MAHONY_DEFAULT_KI` | 0.005 | 积分增益，消除稳态误差 |
| `MAHONY_SAMPLE_FREQ` | 500 Hz | 采样频率 |

---

## 2. 串级 PID 控制器

### 2.1 算法概述

采用串级 PID 控制结构：
- **外环 (角度环)**: 目标角度 → 目标角速度
- **内环 (角速度环)**: 目标角速度 → 电机输出

**文件位置**: [`pid.c`](../FLYAMASTER/Core/Src/pid.c), [`pid.h`](../FLYAMASTER/Core/Inc/pid.h)

### 2.2 数学原理

#### 标准 PID 公式

$$u(t) = K_p e(t) + K_i \int_0^t e(\tau) d\tau + K_d \frac{de(t)}{dt}$$

离散化形式：
$$u[k] = K_p e[k] + K_i \sum_{i=0}^{k} e[i] \Delta t + K_d \frac{e[k] - e[k-1]}{\Delta t}$$

#### 串级控制结构

```
目标角度 ──┬──► [角度环 PID] ──► 目标角速度 ──┬──► [角速度环 PID] ──► 电机输出
           │                                  │
当前角度 ──┘                    当前角速度 ──┘
```

### 2.3 抗积分饱和 (Anti-Windup)

积分项限幅：
$$I_{limited} = \text{clamp}(I, -I_{max}, I_{max})$$

其中 $I_{max} = \frac{\text{integral\_limit}}{K_i}$

### 2.4 微分滤波

使用一阶低通滤波器平滑微分项：

$$D_{filtered}[k] = \alpha \cdot D_{raw}[k] + (1-\alpha) \cdot D_{filtered}[k-1]$$

其中 $\alpha = 0.5$ (可配置)

### 2.5 伪代码

```
function PID_Compute(pid, setpoint, measurement, dt):
    error = setpoint - measurement
    
    // P 项
    p_term = Kp * error
    
    // I 项 (带限幅)
    integral += error * dt
    integral = clamp(integral, -integral_limit/Ki, integral_limit/Ki)
    i_term = Ki * integral
    
    // D 项 (带滤波)
    derivative = (error - prev_error) / dt
    derivative = alpha * derivative + (1-alpha) * prev_derivative
    d_term = Kd * derivative
    
    // 保存状态
    prev_error = error
    prev_derivative = derivative
    
    // 计算输出
    output = p_term + i_term + d_term
    output = clamp(output, -output_limit, output_limit)
    
    return output
```

### 2.6 参数配置

#### 角度环 (外环)

| 轴 | Kp | Ki | Kd | 输出限幅 |
|----|----|----|----|----|
| Roll | 4.0 | 0.02 | 0.0 | ±500 °/s |
| Pitch | 4.0 | 0.02 | 0.0 | ±500 °/s |

#### 角速度环 (内环)

| 轴 | Kp | Ki | Kd | 输出限幅 |
|----|----|----|----|----|
| Roll | 0.7 | 0.3 | 0.02 | ±500 |
| Pitch | 0.7 | 0.3 | 0.02 | ±500 |
| Yaw | 2.0 | 0.5 | 0.0 | ±500 |

---

## 3. 电机混控算法

### 3.1 算法概述

X 型四轴机架的电机混控，将油门和姿态控制量映射到四个电机的 PWM 输出。

**文件位置**: [`motor.c`](../FLYAMASTER/Core/Src/motor.c), [`motor.h`](../FLYAMASTER/Core/Inc/motor.h)

### 3.2 机架布局

```
        前
    M3     M1
      \   /
       \ /
        X
       / \
      /   \
    M2     M4
        后

M1 (右前): CCW (逆时针)
M2 (左后): CCW (逆时针)
M3 (左前): CW  (顺时针)
M4 (右后): CW  (顺时针)
```

### 3.3 混控公式

$$M_1 = T - R - P - Y$$
$$M_2 = T + R + P - Y$$
$$M_3 = T + R - P + Y$$
$$M_4 = T - R + P + Y$$

其中：
- $T$ = 油门 (Throttle)
- $R$ = 横滚控制量 (Roll)
- $P$ = 俯仰控制量 (Pitch)
- $Y$ = 偏航控制量 (Yaw)

### 3.4 Airmode 算法

当电机输出超出范围时，整体偏移以保持姿态控制能力：

```
function Airmode(motor_out[4]):
    max_out = max(motor_out)
    min_out = min(motor_out)
    
    if max_out > PWM_MAX:
        offset = PWM_MAX - max_out
    else if min_out < PWM_IDLE:
        offset = PWM_IDLE - min_out
    else:
        offset = 0
    
    for i in 0..3:
        motor_out[i] += offset
```

### 3.5 PWM 映射

| 参数 | 值 | 说明 |
|---|-----|---|
| `MOTOR_PWM_MIN` | 1000 μs | 电机停止 |
| `MOTOR_PWM_IDLE` | 1100 μs | 怠速 |
| `MOTOR_PWM_MAX` | 2000 μs | 最大油门 |
| `MOTOR_CCR_MIN` | 2000 | TIM8 CCR 最小值 |
| `MOTOR_CCR_MAX` | 4000 | TIM8 CCR 最大值 |

CCR 转换公式：$CCR = PWM \times 2$

---

## 4. 气压高度计算

### 4.1 算法概述

使用 SPL06-001 气压计测量气压，通过国际标准大气模型计算高度。

**文件位置**: [`spl06.c`](../FLYAMASTER/Core/Src/spl06.c), [`spl06.h`](../FLYAMASTER/Core/Inc/spl06.h)

### 4.2 气压高度公式

国际标准大气模型 (ISA)：

$$h = \frac{T_0}{L} \left[ 1 - \left( \frac{P}{P_0} \right)^{\frac{R \cdot L}{g \cdot M}} \right]$$

简化公式：

$$h = 44330 \times \left[ 1 - \left( \frac{P}{P_0} \right)^{0.1903} \right]$$

其中：
- $P$ = 当前气压 (Pa)
- $P_0$ = 海平面气压 (101325 Pa)
- $T_0$ = 海平面温度 (288.15 K)
- $L$ = 温度递减率 (0.0065 K/m)
- $R$ = 气体常数 (8.31447 J/(mol·K))
- $g$ = 重力加速度 (9.80665 m/s²)
- $M$ = 空气摩尔质量 (0.0289644 kg/mol)

### 4.3 温度补偿

SPL06 使用多项式补偿：

$$T_{comp} = \frac{c_0}{2} + c_1 \cdot T_{raw,sc}$$

$$P_{comp} = c_{00} + P_{raw,sc} \cdot (c_{10} + P_{raw,sc} \cdot (c_{20} + P_{raw,sc} \cdot c_{30})) + T_{raw,sc} \cdot c_{01} + T_{raw,sc} \cdot P_{raw,sc} \cdot (c_{11} + P_{raw,sc} \cdot c_{21})$$

其中 $T_{raw,sc}$ 和 $P_{raw,sc}$ 为缩放后的原始值。

### 4.4 高度滤波

一阶低通滤波：

$$h_{filtered}[k] = (1-\alpha) \cdot h_{filtered}[k-1] + \alpha \cdot h_{raw}[k]$$

其中 $\alpha = 0.1$

### 4.5 垂直速度计算

$$v_z = \frac{h_{filtered}[k] - h_{filtered}[k-1]}{\Delta t}$$

---

## 5. 快速数学函数

### 5.1 快速平方根倒数 (Fast Inverse Square Root)

著名的 Quake III 算法，用于四元数归一化：

**文件位置**: [`mahony.c`](../FLYAMASTER/Core/Src/mahony.c) - `InvSqrt()`

```c
float InvSqrt(float x)
{
    float halfx = 0.5f * x;
    float y = x;
    long i = *(long*)&y;
    i = 0x5f3759df - (i >> 1);      // 魔数
    y = *(float*)&i;
    y = y * (1.5f - (halfx * y * y)); // 第一次牛顿迭代
    y = y * (1.5f - (halfx * y * y)); // 第二次牛顿迭代
    return y;
}
```

#### 原理

利用 IEEE 754 浮点数格式的特性，通过位操作快速估计 $1/\sqrt{x}$，然后用牛顿迭代法精化。

牛顿迭代公式：
$$y_{n+1} = y_n \cdot \left( \frac{3}{2} - \frac{x}{2} \cdot y_n^2 \right)$$

---

## 6. 滤波算法

### 6.1 一阶低通滤波器 (LPF)

$$y[k] = \alpha \cdot x[k] + (1-\alpha) \cdot y[k-1]$$

截止频率与 $\alpha$ 的关系：
$$\alpha = \frac{2\pi f_c \Delta t}{1 + 2\pi f_c \Delta t}$$

应用场景：
- 高度滤波 ($\alpha = 0.1$)
- PID 微分滤波 ($\alpha = 0.5$)

### 6.2 互补滤波器

Mahony 算法本质上是一个互补滤波器：
- 高频信号来自陀螺仪积分
- 低频信号来自加速度计

$$\hat{\theta} = \alpha \cdot (\hat{\theta}_{prev} + \omega \cdot \Delta t) + (1-\alpha) \cdot \theta_{acc}$$

---

## 优化记录

### [待记录] 优化项目

| 日期 | 优化内容 | 优化前 | 优化后 | 改进 |
|---|---|---|---|---|
| - | - | - | - | - |

---

## 参考文献

1. Mahony, R., Hamel, T., & Pflimlin, J. M. (2008). Nonlinear complementary filters on the special orthogonal group. *IEEE Transactions on Automatic Control*.

2. Madgwick, S. O. (2010). An efficient orientation filter for inertial and inertial/magnetic sensor arrays. *Report x-io and University of Bristol*.

3. Lomont, C. (2003). Fast inverse square root. *Tech-Report*.

4. International Standard Atmosphere (ISA). *ICAO Doc 7488*.

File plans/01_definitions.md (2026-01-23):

# 🔗 命名规范与接口定义 (Interface Definition)

**创建时间**: 2026-01-16  
**最后更新**: 2026-01-22  
**状态**: 活跃维护中  
**作用**: 防止重复定义、确保命名一致性、统一接口规范

---

## 📋 文档说明

本文档是飞控项目的 **"代码字典"**,记录所有结构体、全局变量、函数原型和宏定义。  
**强制规则**: 每次编写代码前,必须先查阅此文档,严禁臆造变量名或重复定义!

---

## 1. 全局变量命名规范 (Naming Convention)

| 前缀 | 用途 | 示例 | 作用域 |
|:---:|:---|:---|:---|
| `g_` | 通用全局变量 | `g_motor_pwm[4]`, `g_roll` | 跨文件 |
| `Module_` | 模块专属变量 | `SBUS_Data`, `GPS_Data`, `Flow_Data` | 模块内部+外部访问 |
| `volatile` | RTOS共享/ISR访问 | `volatile SPL06_TypeDef SPL06_Data` | 多任务安全 |
| `static` | 文件内私有 | `static uint8_t rx_buffer[256]` | 单文件 |

**规则**:
1. 所有 RTOS 任务之间共享的变量**必须**加 `volatile` 修饰符
2. ISR (中断服务例程) 修改的变量**必须**加 `volatile`
3. 新建全局变量时,优先使用 `Module_` 前缀,如 `Flow_Data`, `QMC_Data`
4. 禁止使用无意义缩写 (如 `temp`, `tmp`, `dat`),必须语义明确

---

## 2. 数据结构定义 (Structure Definitions)

### 2.1 姿态解算模块 (Mahony)

**定义位置**: [`mahony.h:4`](../FLYAMASTER/Core/Inc/mahony.h:4)

```c
typedef struct {
    float q0, q1, q2, q3;  // 四元数 (w, x, y, z)
    float integralFBx, integralFBy, integralFBz; // 积分误差
    float Kp, Ki;  // 算法参数
} Mahony_TypeDef;
```

**成员说明**:
- `q0~q3`: 四元数分量,描述飞机姿态
- `integralFBx/y/z`: 积分误差补偿项 (用于修正陀螺仪零漂)
- `Kp`: 比例增益 (推荐 2.0~5.0)
- `Ki`: 积分增益 (推荐 0.0~0.1)

---

### 2.2 PID 控制器

**定义位置**: [`pid.h:6`](../FLYAMASTER/Core/Inc/pid.h:6)

```c
typedef struct {
    float Kp, Ki, Kd;
    float max_out;      // 输出限幅
    float max_i;        // 积分限幅
    float integral;     // 积分累加值
    float prev_error;   // 上一次误差
    float prev_measure; // 上一次测量值 (用于微分先行)
} PID_TypeDef;
```

**函数接口**:
```c
void PID_Init(PID_TypeDef *pid, float kp, float ki, float kd, float max_out, float max_i);
void PID_Reset(PID_TypeDef *pid);
float PID_Calculate(PID_TypeDef *pid, float target, float measured, float dt);
```

---

### 2.3 遥控器 SBUS 模块

**定义位置**: [`sbus.h:28`](../FLYAMASTER/Core/Inc/sbus.h:28)

```c
typedef struct {
    uint16_t channels[SBUS_CHANNEL_NUMBER]; // 16个通道值 (范围 172~1811)
    uint8_t failsafe; // 失控保护标志 (0:正常, 1:丢帧, 2:失控)
    uint8_t frame_lost;
} SBUS_Data_t;
```

**全局变量**:
```c
extern SBUS_Data_t SBUS_Data;
extern uint8_t SBUS_RxBuffer[SBUS_FRAME_SIZE]; // 25字节
```

**函数接口**:
```c
void SBUS_Init(UART_HandleTypeDef *huart);
void SBUS_Parse(uint8_t *buffer);
uint8_t SBUS_IsConnected(void);
float SBUS_GetThrottle(void);    // 返回 0.0 ~ 1.0
float SBUS_GetRoll(void);        // 返回 -1.0 ~ 1.0
float SBUS_GetPitch(void);       // 返回 -1.0 ~ 1.0
float SBUS_GetYaw(void);         // 返回 -1.0 ~ 1.0
```

---

### 2.4 光流模块

**定义位置**: [`optical_flow.h:14`](../FLYAMASTER/Core/Inc/optical_flow.h:14)

```c
typedef struct {
    int16_t flow_x;         // X轴像素位移
    int16_t flow_y;         // Y轴像素位移
    uint16_t distance;      // 激光测距高度 (mm)
    uint8_t quality;        // 质量 (0~255)
    uint8_t valid;          // 数据有效标志
    uint32_t last_update;   // 最后更新时间
} OpticalFlow_t;
```

**全局变量**:
```c
extern OpticalFlow_t Flow_Data;
```

**函数接口**:
```c
void OpticalFlow_Init(UART_HandleTypeDef *huart);
void OpticalFlow_Parse(uint8_t *buf, uint16_t len);
uint8_t OpticalFlow_GetVelocity(float *vx, float *vy);
float OpticalFlow_GetHeight(void);
```

---

### 2.5 GPS 模块

**定义位置**: [`gps.h:25`](../FLYAMASTER/Core/Inc/gps.h:25)

```c
typedef struct {
    // 定位状态
    uint8_t fix_type;           // 0=无效, 1=GPS定位, 2=DGPS定位
    uint8_t satellites;         // 可见卫星数量
    float hdop;                 // 水平精度因子 (<1.5优秀, <2.5良好, >5差)
    
    // 地理坐标 (小数度格式)
    double latitude;            // 纬度 (°, -90 ~ +90)
    double longitude;           // 经度 (°, -180 ~ +180)
    float altitude;             // 海拔高度 (m, WGS84)
    
    // XY 坐标系 (相对于上电点/Home, 单位:米)
    float pos_x;                // 东向距离 (m, East+)
    float pos_y;                // 北向距离 (m, North+)
    double home_lat;            // Home 点纬度 (°)
    double home_lon;            // Home 点经度 (°)
    uint8_t home_set;           // Home 点已设置标志
    
    // 运动数据
    float speed_kmh;            // 地速 (km/h)
    float course;               // 航向角 (0-360°, 正北=0°)
    
    // 数据质量
    uint8_t valid;              // 数据有效标志
    uint32_t last_update;       // 最后更新时间戳 (ms)
    uint32_t checksum_error_count;  // 校验失败计数 (调试用)
} GPS_Data_t;
```

**全局变量**:
```c
extern GPS_Data_t GPS_Data;
```

**函数接口**:
```c
void GPS_Init(UART_HandleTypeDef *huart);
uint8_t GPS_Validate_Checksum(char* line);
void GPS_Parse_NMEA(char* line);
void GPS_Process_Data(uint8_t* buffer, uint16_t length);
void GPS_To_XY(double lat, double lon, double origin_lat, double origin_lon, float* x, float* y);
void GPS_Set_Home(void);
uint8_t GPS_IsValid(void);
```

---

### 2.6 磁力计 QMC5883L

**定义位置**: [`qmc5883l.h:75`](../FLYAMASTER/Core/Inc/qmc5883l.h:75)

```c
typedef struct {
    // 原始磁场数据 (ADC 读数)
    int16_t mag_x_raw, mag_y_raw, mag_z_raw;
    
    // 校准后的磁场数据 (单位: Gauss)
    float mag_x, mag_y, mag_z;
    
    // 倾斜补偿后的水平磁场
    float mag_x_h, mag_y_h;
    
    // 计算得到的航向角
    float heading;          // 原始航向角 (0~360°)
    float heading_filtered; // 互补滤波后的航向角
    
    // 磁干扰检测
    float mag_strength;     // 磁场强度 (Gauss)
    uint8_t interference_detected;  // 干扰标志 (1=干扰)
    
    // 状态标志
    uint8_t data_ready;     // 数据就绪
    uint8_t initialized;    // 初始化完成
    uint32_t last_update;   // 最后更新时间戳
} QMC5883L_t;
```

**全局变量**:
```c
extern volatile QMC5883L_t QMC_Data;
extern volatile QMC5883L_Calibration_t QMC_Calibration;
```

**函数接口**:
```c
uint8_t QMC5883L_Init(I2C_HandleTypeDef *hi2c);
uint8_t QMC5883L_ReadRaw(I2C_HandleTypeDef *hi2c);
float QMC5883L_CalculateHeading(Mahony_TypeDef *mahony);
void QMC5883L_Calibrate(void);
uint8_t QMC5883L_CalibrateUpdate(void);
void QMC5883L_ApplyCalibration(void);

// v1.2.0 新增: 电流补偿接口
void QMC5883L_CompensateCurrent(float throttle);
void QMC5883L_SetCurrentCompensation(float kx, float ky, float kz);
```

**电流补偿说明** (v1.2.0 新增):
- 公式: `Mag_corrected = Mag_raw - Throttle × K`
- 用于补偿电机电流产生的磁场干扰
- 标定方法: 飞机静止，记录不同油门下的磁场读数，计算 K 系数

---

### 2.7 气压计 SPL06

**定义位置**: [`spl06.h:77`](../FLYAMASTER/Core/Inc/spl06.h:77)

```c
typedef struct {
    // 校准系数 (从芯片读取)
    int16_t c0, c1;
    int32_t c00, c10;
    int16_t c01, c11, c20, c21, c30;
    
    // 测量结果
    float pressure;         // 气压 (Pa)
    float temperature;      // 温度 (°C)
    float altitude;         // 海拔高度 (m)
    
    // 参考值 (用于相对高度计算)
    float pressure_ref;     // 参考气压 (上电时的气压)
    float altitude_ref;     // 参考高度 (设为 0)
    
    // 状态标志
    uint8_t initialized;    // 初始化完成标志
    uint8_t data_ready;     // 数据就绪标志
    uint32_t last_update;   // 最后更新时间 (ms)
} SPL06_TypeDef;
```

**全局变量**:
```c
extern volatile SPL06_TypeDef SPL06_Data; // Risk #066: 添加 volatile
```

**函数接口**:
```c
uint8_t SPL06_Init(I2C_HandleTypeDef *hi2c);
uint8_t SPL06_ReadRawData(I2C_HandleTypeDef *hi2c);
float SPL06_PressureToAltitude(float pressure, float pressure_ref);
float SPL06_GetAltitude(volatile SPL06_TypeDef *spl06);
void SPL06_SetReference(volatile SPL06_TypeDef *spl06);
```

---

### 2.8 Flash 参数管理

**定义位置**: [`flash_params.h:70`](../FLYAMASTER/Core/Inc/flash_params.h:70)

```c
typedef struct __attribute__((packed)) {
    // Header (16 字节)
    uint32_t magic;       // 魔数: 0x464C4159 ("FLAY")
    uint16_t version;     // 版本号 (用于双缓冲区选择)
    uint16_t crc16;       // CRC16 校验值
    uint32_t total_size;  // 数据总大小 (用于校验)
    uint32_t reserved1;   // 保留
    
    // PID 参数 (120 字节)
    PID_Params_t pid_roll_angle;
    PID_Params_t pid_roll_rate;
    PID_Params_t pid_pitch_angle;
    PID_Params_t pid_pitch_rate;
    PID_Params_t pid_yaw_angle;
    PID_Params_t pid_yaw_rate;
    PID_Params_t pid_pos_x;
    PID_Params_t pid_pos_y;
    PID_Params_t pid_alt_pos;
    PID_Params_t pid_alt_vel;
    
    // 校准数据 (76 字节)
    float gyro_offset[3];
    float accel_offset[3];
    float mag_calib[12];
    float pressure_ref;
    
    // 飞行配置 (24 字节)
    float hover_throttle;
    uint8_t channel_map[16];
    uint8_t flight_mode_memory;
    uint8_t reserved2[7];
    
    // 系统信息 (16 字节)
    uint32_t total_flight_time;
    uint8_t fw_version[4];
    uint32_t save_count;
    uint32_t reserved3;
} FlashParams_t;
```

**全局变量**:
```c
extern FlashParams_t g_flash_params;  // 全局参数实例
extern uint8_t g_params_dirty;        // 参数脏标志 (需要保存)
```

**函数接口**:
```c
uint8_t FlashParams_Init(void);
uint8_t FlashParams_Load(void);
uint8_t FlashParams_Save(void);
void FlashParams_RestoreDefaults(void);
void FlashParams_ApplyToPID(void);
void FlashParams_ReadFromPID(void);
void FlashParams_PeriodicSave(void);
```

---

### 2.9 匿名上位机 V7 协议

**定义位置**: [`ano_v7.h:43`](../FLYAMASTER/Core/Inc/ano_v7.h:43)

```c
// 姿态数据帧 (0x01) - 18字节
typedef struct {
    int16_t roll;      // 横滚角 ×100 (度)
    int16_t pitch;     // 俯仰角 ×100 (度)
    int16_t yaw;       // 航向角 ×100 (度)
    int32_t alt;       // 高度 ×100 (cm)
    int16_t vx;        // X速度 ×100 (m/s)
    int16_t vy;        // Y速度 ×100 (m/s)
    int16_t vz;        // Z速度 ×100 (m/s)
} __attribute__((packed)) AnoV7_Attitude_t;

// GPS数据帧 (0x09) - 22字节
typedef struct {
    int32_t  latitude;   // 纬度 ×10^7 (度)
    int32_t  longitude;  // 经度 ×10^7 (度)
    int32_t  altitude;   // 海拔高度 ×100 (cm, WGS84)
    uint16_t speed;      // 地速 ×100 (cm/s)
    uint16_t course;     // 航向角 ×100 (度, 0-36000)
    uint8_t  satellites; // 可见卫星数量
    uint8_t  fix_type;   // 定位类型 (0=无效, 1=GPS, 2=DGPS)
    uint16_t hdop;       // HDOP ×100 (水平精度因子)
    uint8_t  valid;      // 数据有效标志
    uint8_t  reserved;   // 保留字节(对齐)
} __attribute__((packed)) AnoV7_GPS_t;
```

**函数接口**:
```c
void AnoV7_Init(UART_HandleTypeDef *huart);
void AnoV7_SendAttitude(void);
void AnoV7_SendSensor(void);
void AnoV7_SendMotor(void);
void AnoV7_SendStatus(void);
void AnoV7_SendGPS(void);
void AnoV7_Parse(uint8_t *buf, uint16_t len);
void AnoV7_RegisterPIDCallback(AnoV7_PID_Callback callback);
```

---

### 2.10 滤波器模块

**定义位置**: [`filter.h:7`](../FLYAMASTER/Core/Inc/filter.h:7)

```c
typedef struct {
    float b0, b1, b2;  // 前馈系数
    float a1, a2;      // 反馈系数
    float x1, x2;      // 输入历史
    float y1, y2;      // 输出历史
} LPF2_TypeDef;
```

**函数接口**:
```c
void LPF2_Init(LPF2_TypeDef *lpf, float sample_freq, float cutoff_freq);
float LPF2_Apply(LPF2_TypeDef *lpf, float input);
```

---

### 2.11 OSD 模块 (AT7456E)

**定义位置**: [`at7456e.h:20`](../FLYAMASTER/Core/Inc/at7456e.h:20)

```c
typedef struct {
    uint8_t initialized;      // 初始化完成标志
    uint8_t video_detected;   // 视频信号检测标志
    uint8_t video_standard;   // 视频制式 (1=PAL, 2=NTSC)
    uint32_t last_update;     // 最后更新时间
} OSD_Data_t;
```

**全局变量**:
```c
extern OSD_Data_t OSD_Data;
```

**函数接口**:
```c
uint8_t AT7456E_Init(SPI_HandleTypeDef *hspi);
void AT7456E_Update(void);
void AT7456E_Clear(void);
void AT7456E_WriteString(uint8_t row, uint8_t col, const char *str);
```

---

### 2.12 RingBuffer 异步日志模块

**定义位置**: [`ring_buffer.h:15`](../FLYAMASTER/Core/Inc/ring_buffer.h:15)

```c
#define RING_BUFFER_SIZE 512  // 缓冲区大小

typedef struct {
    uint8_t buffer[RING_BUFFER_SIZE];
    volatile uint16_t head;      // 写入位置 (生产者)
    volatile uint16_t tail;      // 读取位置 (DMA 消费者)
    volatile uint8_t dma_busy;   // DMA 忙标志
    UART_HandleTypeDef *huart;   // 关联的 UART 句柄
} RingBuffer_t;
```

**函数接口**:
```c
void RingBuffer_Init(UART_HandleTypeDef *huart);
uint16_t RingBuffer_Write(const uint8_t *data, uint16_t len);
void RingBuffer_StartDMA(void);
void RingBuffer_DMA_TxCpltCallback(void);
int Log_Printf(const char *format, ...);  // 非阻塞 printf 替代
```

**使用说明**:
- 替代阻塞式 `printf`，解决 Issue #111 (高频任务中的控制回路抖动)
- 使用 DMA2_Stream7 (USART1_TX) 进行异步传输
- 在 `HAL_UART_TxCpltCallback` 中调用 `RingBuffer_DMA_TxCpltCallback()`

---

### 2.13 调试工具模块

**定义位置**: [`debug_tools.h:15`](../FLYAMASTER/Core/Inc/debug_tools.h:15)

```c
// I2C 扫描结果结构体
typedef struct {
    uint8_t found_count;        // 发现的设备数量
    uint8_t addresses[16];      // 发现的设备地址 (最多 16 个)
} I2C_ScanResult_t;

// 磁力计电流补偿标定状态
typedef enum {
    MAG_CALIB_IDLE = 0,         // 空闲状态
    MAG_CALIB_COLLECTING_LOW,   // 采集低油门数据
    MAG_CALIB_COLLECTING_HIGH,  // 采集高油门数据
    MAG_CALIB_CALCULATING,      // 计算补偿系数
    MAG_CALIB_DONE              // 标定完成
} MagCalibState_t;

// 磁力计电流补偿标定数据
typedef struct {
    MagCalibState_t state;      // 当前状态
    float mag_x_low, mag_y_low, mag_z_low;   // 低油门采样
    float mag_x_high, mag_y_high, mag_z_high; // 高油门采样
    float throttle_low, throttle_high;        // 油门值
    uint16_t sample_count_low, sample_count_high;
    float k_x, k_y, k_z;        // 计算得到的补偿系数
    uint8_t valid;              // 标定结果有效标志
} MagCurrentCalib_t;
```

**全局变量**:
```c
extern MagCurrentCalib_t g_mag_current_calib;
```

**函数接口**:
```c
// I2C 总线扫描
uint8_t I2C_ScanBus(I2C_HandleTypeDef *hi2c, I2C_ScanResult_t *result);
void I2C_PrintScanResult(I2C_ScanResult_t *result);
void I2C_ScanAllBuses(void);

// 磁力计电流补偿标定
void MagCurrentCalib_Start(void);
void MagCurrentCalib_Update(float mag_x, float mag_y, float mag_z, float throttle);
MagCalibState_t MagCurrentCalib_GetState(void);
void MagCurrentCalib_PrintResult(void);
```

---

## 3. 驱动模块配置参数 (Driver Configuration)

### 3.1 MPU6050 (IMU)

| 参数 | 值 | 说明 |
|---|-----|---|
| **通信接口** | I2C1 | 400kHz Fast Mode |
| **陀螺仪量程** | ±2000 dps | 高动态范围 |
| **加速度计量程** | ±8g | 适合穿越机 |
| **采样率** | 1kHz | SMPLRT_DIV = 0 |
| **DLPF** | 42Hz | 平衡延迟与噪声 |
| **驱动文件** | `mpu6050.c`, `mpu6050.h` | - |
| **关键函数** | `MPU6050_Read_All_Calibrated()` | - |

### 3.2 SPL06-001 (气压计)

| 参数 | 值 | 说明 |
|---|-----|---|
| **通信接口** | I2C1 | 与 MPU6050 共享 |
| **气压采样率** | 32Hz | 16x 过采样 |
| **温度采样率** | 32Hz | 1x 过采样 |
| **驱动文件** | `spl06.c`, `spl06.h` | - |
| **关键函数** | `SPL06_ReadRawData()` | - |

### 3.3 QMC5883L (磁力计)

| 参数 | 值 | 说明 |
|---|-----|---|
| **通信接口** | I2C2 | 独立总线，避免干扰 |
| **采样率** | 50Hz | 连续测量模式 |
| **量程** | ±2 Gauss | 默认量程 |
| **驱动文件** | `qmc5883l.c`, `qmc5883l.h` | - |
| **关键函数** | `QMC5883L_ReadRaw()`, `QMC5883L_CalculateHeading()` | - |

### 3.4 AT7456E (OSD)

| 参数 | 值 | 说明 |
|---|-----|---|
| **通信接口** | SPI1 | 10.5MHz |
| **视频制式** | PAL/NTSC | 自动检测 |
| **刷新率** | 10Hz | 在 comm_task 中更新 |
| **驱动文件** | `at7456e.c`, `at7456e.h` | - |
| **关键函数** | `AT7456E_Update()` | - |

### 3.5 GPS (ATGM336H)

| 参数 | 值 | 说明 |
|---|-----|---|
| **通信接口** | USART2 | 115200 baud |
| **协议** | NMEA 0183 | GNGGA, GNRMC |
| **驱动文件** | `gps.c`, `gps.h` | - |
| **关键函数** | `GPS_Parse_NMEA()` | - |

---

## 4. 宏定义 (Macro Definitions)

### 4.1 电机控制

**定义位置**: [`motor.h:6`](../FLYAMASTER/Core/Inc/motor.h:6)

```c
#define MOTOR_MIN_PWM 1000
#define MOTOR_MAX_PWM 2000
#define MOTOR_IDLE_PWM 1100 // 怠速 (AirMode)
```

---

### 4.2 光流参数

**定义位置**: [`optical_flow.h:6`](../FLYAMASTER/Core/Inc/optical_flow.h:6)

```c
#define FLOW_SCALE_FACTOR   0.01f    // 缩放系数 (需根据模块校准)
#define FLOW_MIN_HEIGHT     0.05f    // 最小有效高度 5cm
#define FLOW_MAX_HEIGHT     3.0f     // 最大有效高度 3m
#define FLOW_MIN_QUALITY    30       // 最小有效质量
```

---

### 4.3 SBUS 协议

**定义位置**: [`sbus.h:6`](../FLYAMASTER/Core/Inc/sbus.h:6)

```c
#define SBUS_FRAME_SIZE 25
#define SBUS_CHANNEL_NUMBER 16
#define SBUS_MIN_VALUE   172
#define SBUS_MID_VALUE   992
#define SBUS_MAX_VALUE   1811

// 通道映射定义
#define CH_ROLL     0   // 横滚 (Aileron)
#define CH_PITCH    1   // 俯仰 (Elevator)
#define CH_THROTTLE 2   // 油门 (Throttle)
#define CH_YAW      3   // 偏航 (Rudder)
#define CH_ARM      4   // 解锁开关
#define CH_MODE     5   // 飞行模式开关
```

---

### 4.4 GPS 参数

**定义位置**: [`gps.h:7`](../FLYAMASTER/Core/Inc/gps.h:7)

```c
#define GPS_MIN_SATELLITES      4       // 最少卫星数
#define GPS_MAX_HDOP            2.5f    // 最大水平精度因子
#define GPS_TIMEOUT_MS          1000    // GPS 数据超时 (ms)
#define GPS_RX_BUF_SIZE        256      // NMEA 句子长度 <80字符
#define EARTH_RADIUS_M         6378137.0 // 地球半径 (米)
```

---

### 4.5 磁力计参数

**定义位置**: [`qmc5883l.h:8`](../FLYAMASTER/Core/Inc/qmc5883l.h:8)

```c
#define QMC5883L_ADDR       (0x0D << 1)  // 7-bit: 0x0D
#define MAG_DECLINATION     -3.5f        // 磁偏角 (度, 根据当地调整)
```

---

### 4.6 气压计参数

**定义位置**: [`spl06.h:18`](../FLYAMASTER/Core/Inc/spl06.h:18)

```c
#define SPL06_ADDR              (0x76 << 1)  // SDO=GND: 0x76
#define SPL06_ADDR_ALT          (0x77 << 1)  // SDO=VDD: 0x77
#define SPL06_PRODUCT_ID        0x10
```

---

### 4.7 Flash 参数

**定义位置**: [`flash_params.h:113`](../FLYAMASTER/Core/Inc/flash_params.h:113)

```c
#define FLASH_PARAMS_ADDR_A    0x000000  // Block A 地址
#define FLASH_PARAMS_ADDR_B    0x000200  // Block B 地址 (512 字节偏移)
#define FLASH_PARAMS_MAGIC     0x464C4159  // "FLAY"
#define FLASH_PARAMS_VERSION   1           // 当前版本号
#define FLASH_SAVE_DELAY_MS    2000        // 修改后延迟 2 秒保存
```

---

### 4.8 匿名上位机协议

**定义位置**: [`ano_v7.h:20`](../FLYAMASTER/Core/Inc/ano_v7.h:20)

```c
#define ANO_V7_FRAME_HEADER1    0xAA    // 帧头1
#define ANO_V7_FRAME_HEADER2    0xAF    // 帧头2

// 功能字定义
#define ANO_V7_FUNC_ATTITUDE    0x01    // 姿态数据帧 (FC→PC)
#define ANO_V7_FUNC_SENSOR      0x02    // 传感器数据帧 (FC→PC)
#define ANO_V7_FUNC_MOTOR       0x04    // 电机PWM帧 (FC→PC)
#define ANO_V7_FUNC_STATUS      0x05    // 状态数据帧 (FC→PC)
#define ANO_V7_FUNC_GPS         0x09    // GPS数据帧 (FC→PC)
#define ANO_V7_FUNC_PID_READ    0x10    // 读取PID (PC→FC)
#define ANO_V7_FUNC_PID_WRITE   0x11    // 写入PID (PC→FC)
#define ANO_V7_FUNC_PID_DATA    0x12    // PID数据帧 (FC→PC)

// 错误码定义 (位掩码格式)
#define ANO_ERROR_NONE          0x0000  // 无错误
#define ANO_ERROR_IMU_FAIL      0x0001  // IMU 初始化/通信失败
#define ANO_ERROR_BARO_FAIL     0x0002  // 气压计初始化/通信失败
#define ANO_ERROR_MAG_FAIL      0x0004  // 磁力计初始化/通信失败
#define ANO_ERROR_GPS_TIMEOUT   0x0008  // GPS 数据超时 (>3s)
#define ANO_ERROR_RC_LOST       0x0010  // 遥控器信号丢失
#define ANO_ERROR_LOW_BATTERY   0x0020  // 电池电压过低 (<10.5V)
#define ANO_ERROR_MOTOR_LOCK    0x0040  // 电机锁定/堵转
#define ANO_ERROR_FLASH_FAIL    0x0080  // Flash 读写失败
#define ANO_ERROR_SENSOR_CALIB  0x0100  // 传感器需要校准
#define ANO_ERROR_ATTITUDE_ERR  0x0200  // 姿态解算异常 (>60°)
#define ANO_ERROR_FAILSAFE      0x0400  // Failsafe 触发
#define ANO_ERROR_ARMING_BLOCK  0x0800  // 解锁被阻止 (安全检查未通过)
```

---

### 4.9 OSD 参数

**定义位置**: [`at7456e.h:10`](../FLYAMASTER/Core/Inc/at7456e.h:10)

```c
#define OSD_MAX_ROWS_PAL    16
#define OSD_MAX_COLS_PAL    30
#define OSD_CHAR_SPACE      0x00
```

---

## 5. 外设句柄命名规范 (Peripheral Handles) - STM32F405RGT6

| 外设 | 句柄名称 | 引脚分配 | 用途 | DMA |
|:---:|:---|:---|:---|:---|
| **USART1** | `huart1` | PA9/PA10 | 树莓派/日志 (921600 baud) | DMA2_Stream7 TX, DMA2_Stream2 RX |
| **USART2** | `huart2` | PA2/PA3 | GPS 模块 (115200 baud) | DMA1_Stream5 RX (Circular) |
| **UART4** | `huart4` | PC10/PC11 | SBUS (100k, Even, 2Stop) + SmartAudio | DMA1_Stream2 RX, DMA1_Stream4 TX |
| **UART5** | `huart5` | PC12/PD2 | 光流模块 / 匿名上位机 (115200 baud) | DMA1_Stream7 TX |
| **I2C1** | `hi2c1` | PB6/PB7 | MPU6050 + SPL06 (400kHz) | DMA1_Stream0 RX, DMA1_Stream6 TX |
| **I2C2** | `hi2c2` | PB10/PB11 | QMC5883L 磁力计 (100kHz) | DMA1_Stream3 RX |
| **SPI1** | `hspi1` | PA5/PA6/PA7 | W25Q128 + AT7456E (10.5MHz) | DMA2_Stream0 RX, DMA2_Stream3 TX |
| **TIM1** | `htim1` | PA8 (CH1) | WS2812 RGB 灯 (PWM) | DMA2_Stream1 |
| **TIM4** | `htim4` | - | HAL 时基 (Timebase Source) | - |
| **TIM8** | `htim8` | PC6-PC9 (CH1-4) | 电机 PWM (400Hz) | - |
| **ADC1** | `hadc1` | PC0 (IN10), PC5 (IN15) | 电池电压+电流 | DMA2_Stream4 (Circular) |
| **USB_OTG_FS** | `hpcd_USB_OTG_FS` | PA11/PA12 | CDC 虚拟串口 | - |
| **GPIO** | `BUZZER` | PC2 | 蜂鸣器 (Output) | - |
| **GPIO** | `LED_BLUE` | PC3 | 蓝色 LED (Output) | - |
| **GPIO** | `LED_RED` | PC4 | 红色 LED (Output) | - |
| **GPIO** | `FLASH_CS` | PA4 | Flash 片选 (Output, High) | - |
| **GPIO** | `OSD_CS` | PB12 | OSD 片选 (Output, High) | - |

**规则**:
- **严禁臆造外设句柄**! 例如文档里只定义了 `huart4`,代码里不能写 `huart6`
- 如需新增外设,必须先更新 [`08_hardware_design.md`](08_hardware_design.md)
- **注意**: F405 没有 UART6，GPS 使用 USART2，SBUS 使用 UART4

---

## 6. 函数命名规范 (Function Naming)

| 模块 | 命名格式 | 示例 |
|:---:|:---|:---|
| 初始化函数 | `Module_Init()` | `GPS_Init()`, `QMC5883L_Init()` |
| 数据读取 | `Module_Read*()` | `SPL06_ReadRawData()`, `QMC5883L_ReadRaw()` |
| 数据解析 | `Module_Parse()` | `GPS_Parse_NMEA()`, `SBUS_Parse()` |
| 数据获取 | `Module_Get*()` | `SBUS_GetThrottle()`, `Flow_GetVelocity()` |
| 校准函数 | `Module_Calibrate()` | `QMC5883L_Calibrate()`, `SPL06_SetReference()` |
| 计算函数 | `Module_Calculate*()` | `QMC5883L_CalculateHeading()`, `PID_Calculate()` |
| 发送函数 | `Module_Send*()` | `AnoV7_SendAttitude()`, `AnoV7_SendGPS()` |

---

## 7. 更新日志 (Update Log)

| 日期 | 变更内容 | 责任人 |
|:---:|:---|:---|
| 2026-01-16 | 创建接口定义文档 | Doro |
| 2026-01-16 | 添加 GPS 模块接口 | Doro |
| 2026-01-16 | 添加 QMC5883L 磁力计接口 | Doro |
| 2026-01-16 | 添加 Flash 参数管理接口 | Doro |
| 2026-01-16 | 添加匿名上位机 V7 协议接口 | Doro |
| 2026-01-18 | 添加 RingBuffer 异步日志模块 | Doro |
| 2026-01-18 | 添加 QMC5883L 电流补偿接口 | Doro |
| 2026-01-18 | 更新 Motor_Mix Airmode 算法说明 | Doro |
| 2026-01-18 | 更新 PID Anti-windup 算法说明 | Doro |
| 2026-01-18 | 添加调试工具模块 (I2C 扫描 + 磁力计标定) | Doro |
| 2026-01-18 | 添加 AnoV7 错误码定义 (12 个错误码) | Doro |
| 2026-01-22 | 文档整合: 重命名为 01_definitions.md | Kilo Code |
| 2026-01-22 | 合并驱动模块配置参数 (从 04_Module_Drivers_Deep_Dive.md) | Kilo Code |

---

## 8. 冲突检查清单 (Conflict Checklist)

在创建新变量/函数前,必须检查:

- [ ] 是否已在本文档中定义过?
- [ ] 命名是否符合项目规范? (前缀、语义)
- [ ] 是否需要 `volatile` 修饰? (RTOS/ISR 共享)
- [ ] 是否需要 `extern` 声明? (跨文件访问)
- [ ] 是否需要 `__attribute__((packed))`? (网络协议/Flash存储)
- [ ] 是否需要更新 [`08_hardware_design.md`](08_hardware_design.md)?

---

**使用规范**:
1. 每次编写代码前,**必须**先查阅此文档
2. 如果发现文档中没有你需要的接口,**必须**先更新此文档再写代码
3. 修改结构体定义时,**必须**同步更新 [`04_algo_design.md`](04_algo_design.md)
4. 发现重复定义时,立即报告并在 [`03_issue_tracker.md`](03_issue_tracker.md) 中记录

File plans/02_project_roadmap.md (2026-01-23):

# 📅 项目路线图 (Project Roadmap)

**创建时间**: 2026-01-22  
**最后更新**: 2026-01-22  
**状态**: 🟢 进行中 (In Progress)

---

## 📋 文档说明

本文档记录项目的里程碑、待办事项和架构演进计划。  
**格式规范**: 使用 `- [ ]` 表示待办，`- [x]` 表示已完成，`~~删除线~~` 表示废弃。

---

## 🎯 项目愿景 (Vision)

打造一款基于 STM32F405 的高性能、开源、易扩展的四轴飞行控制器，支持 GPS 定点、光流悬停和 OSD 显示，适用于教育和科研。

---

## ✅ Phase 1: 基础飞行 (Basic Flight) [已完成]

**目标**: 实现基本的姿态稳定和定高飞行

- [x] 硬件驱动开发
  - [x] MPU6050 IMU 驱动 (I2C DMA)
  - [x] SPL06 气压计驱动
  - [x] SBUS 遥控器接收 (UART4 DMA)
  - [x] 电机 PWM 输出 (TIM8, 400Hz)
- [x] 姿态解算
  - [x] Mahony 互补滤波算法 (500Hz)
  - [x] 四元数转欧拉角
  - [x] 陀螺仪零漂校准
- [x] 姿态控制
  - [x] 串级 PID 控制器 (角度环 + 角速度环)
  - [x] 电机混控算法 (X 型四轴)
  - [x] Airmode 怠速保护
- [x] 基础定高
  - [x] 气压计高度解算
  - [x] 高度环 PID 控制
  - [x] 油门曲线映射

---

## ✅ Phase 2: 进阶功能 (Advanced Features) [已完成]

**目标**: 实现室内外定位和 FPV 显示

- [x] 光流定位
  - [x] LC302 光流模块驱动
  - [x] 光流数据高度补偿
  - [x] 位置环 PID 控制
- [x] GPS 导航
  - [x] ATGM336H GPS 驱动 (USART2 DMA)
  - [x] NMEA 协议解析 (GNGGA, GNRMC)
  - [x] GPS 坐标转 XY 平面坐标
  - [x] GPS 位置环 PID 控制
- [x] OSD 显示
  - [x] AT7456E 驱动 (SPI1)
  - [x] 飞行模式显示
  - [x] 姿态/电压/GPS 状态显示
- [x] 磁力计集成
  - [x] QMC5883L 驱动 (I2C2)
  - [x] 8 字校准算法
  - [x] 倾斜补偿航向计算
- [x] 参数存储
  - [x] W25Q128 Flash 驱动 (SPI1)
  - [x] 双缓冲区参数存储
  - [x] CRC16 校验
- [x] 上位机通信
  - [x] 匿名上位机 V7 协议
  - [x] 实时数据上传
  - [x] PID 参数在线调整

---

## 🚧 Phase 3: 智能化与优化 (Intelligence & Optimization) [进行中]

**目标**: 提升飞行性能和安全性

### 3.1 安全强化 (Safety Hardening)
- [x] 异步日志系统 (RingBuffer + DMA)
- [x] 移除高频任务中的阻塞式 printf
- [ ] 失控保护 (Failsafe) 逻辑升级
  - [ ] Stage 1: 信号丢失 < 1s → 保持姿态
  - [ ] Stage 2: 信号丢失 > 1s → 自稳模式 + 降落油门
  - [ ] Stage 3: 信号丢失 > 5s → 强制停机
- [ ] 解锁前 GPS 强制检查 (Arming Check)
- [ ] 磁力计电流补偿集成

### 3.2 算法优化 (Algorithm Optimization)
- [ ] D 项滤波参数优化 (30Hz → 40Hz 可选)
- [ ] 积分抗饱和 (Anti-Windup) 条件积分
- [ ] ~~EKF 状态估计~~ (暂缓，算力不足)

### 3.3 功能扩展 (Feature Extension)
- [ ] 航点飞行 (Waypoint Mission)
- [ ] 自动返航 (RTH)
- [ ] 视觉避障 (配合树莓派)
- [ ] WS2812 RGB 灯效

---

## 📋 Phase 4: 硬件设计 (Hardware Design) [待开始]

**目标**: 完成 PCB 设计和打样验证

### 4.1 原理图设计
- [ ] 电源管理模块
  - [ ] SY8303 DCDC 降压 (5V BEC)
  - [ ] RT9193 LDO (3.3V)
  - [ ] 软开关电路
  - [ ] USB 反灌保护
- [ ] MCU 最小系统
  - [ ] STM32F405RGT6 (LQFP-64)
  - [ ] 8MHz HSE 晶振
  - [ ] SWD 调试接口
- [ ] 传感器模块
  - [ ] MPU6050 + SPL06 (I2C1)
  - [ ] QMC5883L (I2C2)
- [ ] 接口设计
  - [ ] 电机输出 (SH1.0-3P × 4)
  - [ ] GPS 接口 (SH1.0-6P)
  - [ ] 光流接口 (SH1.0-4P)
  - [ ] SBUS 接口 (SH1.0-3P)
  - [ ] USB Type-C

### 4.2 PCB 布局
- [ ] 4 层板设计 (Top/GND/PWR/Bottom)
- [ ] 30.5mm × 30.5mm 标准尺寸
- [ ] M3 安装孔
- [ ] 电源完整性检查
- [ ] 信号完整性检查

### 4.3 打样验证
- [ ] 首版 PCB 打样
- [ ] 焊接与调试
- [ ] 功能验证
- [ ] 问题记录与改版

---

## 📋 Phase 5: 产品化 (Productization) [计划中]

**目标**: 完善文档和用户体验

- [ ] 用户手册编写
- [ ] 固件升级工具 (DFU)
- [ ] 配置工具 (PC 端)
- [ ] 开源发布 (GitHub)
- [ ] CSDN 博客教程

---

## 🗓️ 里程碑时间线 (Milestones)

| 阶段 | 目标 | 状态 | 完成日期 |
|---|---|---|---|
| Phase 1 | 基础飞行 | ✅ 完成 | 2026-01-14 |
| Phase 2 | 进阶功能 | ✅ 完成 | 2026-01-18 |
| Phase 3 | 智能化优化 | 🚧 进行中 | - |
| Phase 4 | 硬件设计 | ⏳ 待开始 | - |
| Phase 5 | 产品化 | 📋 计划中 | - |

---

## 📝 废弃方案记录 (Deprecated Plans)

### ~~EKF 状态估计~~
- **废弃时间**: 2026-01-18
- **废弃原因**: STM32F405 算力不足，运行完整 EKF 会占用 60-80% CPU
- **替代方案**: 保留 Mahony 互补滤波，仅在高度环和位置环使用简化 EKF

### ~~STM32F407VGT6 方案~~
- **废弃时间**: 2026-01-16
- **废弃原因**: LQFP-100 封装过大，不适合 Mini 飞控
- **替代方案**: 迁移到 STM32F405RGT6 (LQFP-64)

---

## 📌 更新日志

| 日期 | 变更内容 | 责任人 |
|---|---|---|
| 2026-01-22 | 创建项目路线图文档 | Kilo Code |
| 2026-01-22 | 从 01_Project_Master_Plan.md 迁移内容 | Kilo Code |

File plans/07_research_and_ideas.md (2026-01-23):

# 💡 Research & Ideas (调研分析与创意池)

**创建时间**: 2026-01-18  
**状态**: 活跃维护中  
**作用**: 收集 AI 建议、竞品对比、头脑风暴与算力评估

---

## 🧠 1. 芯片算力评估 (STM32F407ZGT6)

### 1.1 核心规格
*   **Core**: ARM Cortex-M4F (带 FPU)
*   **Frequency**: 168 MHz
*   **Flash**: 1 MB
*   **RAM**: 192 KB (128KB System + 64KB CCM)
*   **Performance**: 210 DMIPS (1.25 DMIPS/MHz)

### 1.2 负载估算 (Load Estimation)

| 任务 (Task) | 频率 (Hz) | 耗时估算 (us) | CPU 占用率 (%) | 备注 |
| :--- | :--- | :--- | :--- | :--- |
| **IMU Task** | 500 | 400 | 20.0% | 姿态解算(Mahony) + 滤波 |
| **Control Task** | 250 | 200 | 5.0% | 串级 PID + 混控 |
| **Comm Task** | 100 | 500 | 5.0% | 协议解析 + 数据打包 |
| **GPS Parsing** | 10 | 2000 | 2.0% | NMEA 解析 (字符串处理耗时) |
| **OSD Update** | 10 | 3000 | 3.0% | SPI 刷屏 (耗时较长) |
| **Interrupts** | - | - | 10.0% | UART/I2C/Timer 中断开销 |
| **FreeRTOS** | 1000 | - | 5.0% | 调度器开销 |
| **Total** | - | - | **~50.0%** | **理论安全** |

### 1.3 瓶颈分析 (Bottlenecks)
1.  **浮点运算**: 虽然有 FPU，但 `atan2`, `sin`, `cos` 等三角函数依然消耗较大周期。建议开启 `Fast Math` 库。
2.  **I/O 阻塞**: 目前 `printf` 和部分 I2C 操作是阻塞的。如果 I2C 超时（如磁力计掉线），可能导致 `imu_task` 卡顿 10ms 以上，直接导致炸机。
3.  **字符串处理**: GPS 的 NMEA 协议是 ASCII 码，解析需要大量 `sscanf` 或 `strtok`，效率低下。建议使用 DMA 接收 + 状态机解析。

### 1.4 结论
*   **算力足够**: STM32F407 足以支撑目前的飞控业务（姿态+导航）。
*   **风险点**: **阻塞式 I/O** 是最大隐患。必须将所有传感器读取改为 DMA 或中断模式，或者严格限制超时时间。

---

## 🧪 2. 架构优化建议 (AI Suggestions)

### 2.1 EKF (扩展卡尔曼滤波) 可行性深度分析

> Suggestion: 引入 EKF 替代 Mahony 互补滤波

#### 📊 技术对比表

| 特性 | Mahony (当前) | EKF (计划) | 评价 |
| :--- | :--- | :--- | :--- |
| **计算复杂度** | O(1) 简单 | O(n²) 矩阵运算 | EKF 需要大量浮点运算 |
| **CPU 占用** | ~20% @ 500Hz | **~60-80%** @ 250Hz | **风险：可能超负荷** |
| **精度** | 中等 (±2°) | 高 (±0.5°) | EKF 在高动态下更稳定 |
| **磁干扰抑制** | 弱 | 强 (自适应协方差) | EKF 可动态调整传感器权重 |
| **代码复杂度** | 简单 (~200行) | 复杂 (~2000行) | 维护成本高 |
| **内存占用** | ~1KB | ~10KB (状态矩阵) | RAM 占用显著增加 |

#### ⚖️ 可行性评估

**✅ 优势**:
1.  **精度提升**: EKF 能融合 IMU + GPS + 磁力计 + 气压计，提供更准确的状态估计。
2.  **抗干扰**: 通过协方差矩阵自适应调整，能有效抑制磁场干扰和 GPS 漂移。
3.  **行业标准**: PX4、ArduPilot 等成熟飞控都使用 EKF2，技术成熟度高。

**❌ 劣势**:
1.  **算力瓶颈**: STM32F407 @ 168MHz 运行完整 EKF 会占用 **60-80% CPU**，留给控制环的余量不足。
2.  **实时性风险**: 如果 EKF 计算超时，会导致控制周期抖动，严重时炸机。
3.  **调参地狱**: EKF 有 20+ 个参数需要调优 (过程噪声、观测噪声等)，新手容易调崩。

#### 🎯 Doro 的建议方案

**方案 A: 保守路线 (推荐给新手)**
*   **保留 Mahony**: 继续使用 Mahony 进行姿态解算 (500Hz)。
*   **局部 EKF**: 仅在 **高度环** 和 **位置环** 使用简化 EKF (50Hz)，融合气压计、GPS、光流。
*   **优势**: 算力可控 (~30% CPU)，调参简单，稳定性高。

**方案 B: 激进路线 (适合进阶玩家)**
*   **全面 EKF**: 移植 PX4 的 EKF2 (简化版)，融合所有传感器。
*   **降频运行**: IMU 降至 **250Hz**，EKF 运行在 **100Hz**。
*   **硬件升级**: 如果算力不足，考虑升级到 **STM32H743** (480MHz, 双精度 FPU)。
*   **风险**: 开发周期长 (2-3个月)，调参难度大。

#### 🔬 实测数据参考 (来自开源社区)

| 平台 | MCU | EKF 频率 | CPU 占用 | 结果 |
| :--- | :--- | :--- | :--- | :--- |
| PX4 (Pixhawk 4) | STM32F765 (216MHz) | 250Hz | ~40% | ✅ 稳定运行 |
| ArduPilot (Cube Orange) | STM32H743 (480MHz) | 400Hz | ~30% | ✅ 高性能 |
| **本项目 (F407)** | STM32F407 (168MHz) | 250Hz | **~70%** (估算) | ⚠️ 接近极限 |

#### 💡 Doro 的最终建议

**如果指挥官是新手或追求稳定**:
*   **不建议上 EKF**。Mahony + 简单互补滤波已经足够应对大部分场景。
*   优先完成 GPS 导航逻辑、OSD 显示等基础功能。

**如果指挥官想挑战自我**:
*   可以尝试 **方案 A (局部 EKF)**，先在高度环和位置环试水。
*   等技术成熟后，再考虑升级硬件 (H7) 并移植完整 EKF2。

**Doro 的个人意见**:
*   在 F407 上强行上 EKF 就像让一只猫去拉雪橇，虽然理论上可行，但会很累捏！🐱
*   建议先把基础功能做扎实，等需要更高精度时再升级硬件多洛！✨

> Suggestion: 采用 "双缓冲 + DMA" 优化 OSD 刷新

*   **背景**: AT7456E 是 SPI 接口，全屏刷新需要发送大量数据。
*   **方案**: 在内存中开辟 `OSD_Buffer[30][16]`，仅修改显存，然后由 DMA 在后台自动发送到 SPI 总线。
*   **收益**: CPU 零等待，彻底消除 OSD 刷新带来的卡顿风险。

---

## 📊 3. 竞品对比 (Competitor Analysis)

| 特性 | 本项目 (FLYAMASTER) | Betaflight (F405) | PX4 (F427) | 评价 |
| :--- | :--- | :--- | :--- | :--- |
| **RTOS** | FreeRTOS | 裸机 (调度器) | NuttX | FreeRTOS 适合教学与模块化，但上下文切换开销略大。 |
| **算法** | Mahony + PID | PID + 陷波滤波 | EKF2 + 串级PID | 我们的算法最基础，适合入门；PX4 最强但最重。 |
| **开发难度** | 中 (CubeMX+HAL) | 高 (寄存器操作) | 极高 (复杂架构) | 我们的方案在性能与易用性之间取得了平衡。 |

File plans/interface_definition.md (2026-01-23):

# 🔗 接口定义与命名规范 (Interface Definition)

**创建时间**: 2026-01-16  
**状态**: 活跃维护中  
**作用**: 防止重复定义、确保命名一致性、统一接口规范

---

## 📋 文档说明

本文档是飞控项目的 **"代码字典"**,记录所有结构体、全局变量、函数原型和宏定义。  
**强制规则**: 每次编写代码前,必须先查阅此文档,严禁臆造变量名或重复定义!

---

## 1. 全局变量命名规范 (Naming Convention)

| 前缀 | 用途 | 示例 | 作用域 |
|:---:|:---|:---|:---|
| `g_` | 通用全局变量 | `g_motor_pwm[4]`, `g_roll` | 跨文件 |
| `Module_` | 模块专属变量 | `SBUS_Data`, `GPS_Data`, `Flow_Data` | 模块内部+外部访问 |
| `volatile` | RTOS共享/ISR访问 | `volatile SPL06_TypeDef SPL06_Data` | 多任务安全 |
| `static` | 文件内私有 | `static uint8_t rx_buffer[256]` | 单文件 |

**规则**:
1. 所有 RTOS 任务之间共享的变量**必须**加 `volatile` 修饰符
2. ISR (中断服务例程) 修改的变量**必须**加 `volatile`
3. 新建全局变量时,优先使用 `Module_` 前缀,如 `Flow_Data`, `QMC_Data`
4. 禁止使用无意义缩写 (如 `temp`, `tmp`, `dat`),必须语义明确

---

## 2. 数据结构定义 (Structure Definitions)

### 2.1 姿态解算模块 (Mahony)

**定义位置**: [`mahony.h:4`](../FLYAMASTER/Core/Inc/mahony.h:4)

```c
typedef struct {
    float q0, q1, q2, q3;  // 四元数 (w, x, y, z)
    float integralFBx, integralFBy, integralFBz; // 积分误差
    float Kp, Ki;  // 算法参数
} Mahony_TypeDef;
```

**成员说明**:
- `q0~q3`: 四元数分量,描述飞机姿态
- `integralFBx/y/z`: 积分误差补偿项 (用于修正陀螺仪零漂)
- `Kp`: 比例增益 (推荐 2.0~5.0)
- `Ki`: 积分增益 (推荐 0.0~0.1)

---

### 2.2 PID 控制器

**定义位置**: [`pid.h:6`](../FLYAMASTER/Core/Inc/pid.h:6)

```c
typedef struct {
    float Kp, Ki, Kd;
    float max_out;      // 输出限幅
    float max_i;        // 积分限幅
    float integral;     // 积分累加值
    float prev_error;   // 上一次误差
    float prev_measure; // 上一次测量值 (用于微分先行)
} PID_TypeDef;
```

**函数接口**:
```c
void PID_Init(PID_TypeDef *pid, float kp, float ki, float kd, float max_out, float max_i);
void PID_Reset(PID_TypeDef *pid);
float PID_Calculate(PID_TypeDef *pid, float target, float measured, float dt);
```

---

### 2.3 遥控器 SBUS 模块

**定义位置**: [`sbus.h:28`](../FLYAMASTER/Core/Inc/sbus.h:28)

```c
typedef struct {
    uint16_t channels[SBUS_CHANNEL_NUMBER]; // 16个通道值 (范围 172~1811)
    uint8_t failsafe; // 失控保护标志 (0:正常, 1:丢帧, 2:失控)
    uint8_t frame_lost;
} SBUS_Data_t;
```

**全局变量**:
```c
extern SBUS_Data_t SBUS_Data;
extern uint8_t SBUS_RxBuffer[SBUS_FRAME_SIZE]; // 25字节
```

**函数接口**:
```c
void SBUS_Init(UART_HandleTypeDef *huart);
void SBUS_Parse(uint8_t *buffer);
uint8_t SBUS_IsConnected(void);
float SBUS_GetThrottle(void);    // 返回 0.0 ~ 1.0
float SBUS_GetRoll(void);        // 返回 -1.0 ~ 1.0
float SBUS_GetPitch(void);       // 返回 -1.0 ~ 1.0
float SBUS_GetYaw(void);         // 返回 -1.0 ~ 1.0
```

---

### 2.4 光流模块

**定义位置**: [`optical_flow.h:14`](../FLYAMASTER/Core/Inc/optical_flow.h:14)

```c
typedef struct {
    int16_t flow_x;         // X轴像素位移
    int16_t flow_y;         // Y轴像素位移
    uint16_t distance;      // 激光测距高度 (mm)
    uint8_t quality;        // 质量 (0~255)
    uint8_t valid;          // 数据有效标志
    uint32_t last_update;   // 最后更新时间
} OpticalFlow_t;
```

**全局变量**:
```c
extern OpticalFlow_t Flow_Data;
```

**函数接口**:
```c
void OpticalFlow_Init(UART_HandleTypeDef *huart);
void OpticalFlow_Parse(uint8_t *buf, uint16_t len);
uint8_t OpticalFlow_GetVelocity(float *vx, float *vy);
float OpticalFlow_GetHeight(void);
```

---

### 2.5 GPS 模块

**定义位置**: [`gps.h:25`](../FLYAMASTER/Core/Inc/gps.h:25)

```c
typedef struct {
    // 定位状态
    uint8_t fix_type;           // 0=无效, 1=GPS定位, 2=DGPS定位
    uint8_t satellites;         // 可见卫星数量
    float hdop;                 // 水平精度因子 (<1.5优秀, <2.5良好, >5差)
    
    // 地理坐标 (小数度格式)
    double latitude;            // 纬度 (°, -90 ~ +90)
    double longitude;           // 经度 (°, -180 ~ +180)
    float altitude;             // 海拔高度 (m, WGS84)
    
    // XY 坐标系 (相对于上电点/Home, 单位:米)
    float pos_x;                // 东向距离 (m, East+)
    float pos_y;                // 北向距离 (m, North+)
    double home_lat;            // Home 点纬度 (°)
    double home_lon;            // Home 点经度 (°)
    uint8_t home_set;           // Home 点已设置标志
    
    // 运动数据
    float speed_kmh;            // 地速 (km/h)
    float course;               // 航向角 (0-360°, 正北=0°)
    
    // 数据质量
    uint8_t valid;              // 数据有效标志
    uint32_t last_update;       // 最后更新时间戳 (ms)
    uint32_t checksum_error_count;  // 校验失败计数 (调试用)
} GPS_Data_t;
```

**全局变量**:
```c
extern GPS_Data_t GPS_Data;
```

**函数接口**:
```c
void GPS_Init(UART_HandleTypeDef *huart);
uint8_t GPS_Validate_Checksum(char* line);
void GPS_Parse_NMEA(char* line);
void GPS_Process_Data(uint8_t* buffer, uint16_t length);
void GPS_To_XY(double lat, double lon, double origin_lat, double origin_lon, float* x, float* y);
void GPS_Set_Home(void);
uint8_t GPS_IsValid(void);
```

---

### 2.6 磁力计 QMC5883L

**定义位置**: [`qmc5883l.h:75`](../FLYAMASTER/Core/Inc/qmc5883l.h:75)

```c
typedef struct {
    // 原始磁场数据 (ADC 读数)
    int16_t mag_x_raw, mag_y_raw, mag_z_raw;
    
    // 校准后的磁场数据 (单位: Gauss)
    float mag_x, mag_y, mag_z;
    
    // 倾斜补偿后的水平磁场
    float mag_x_h, mag_y_h;
    
    // 计算得到的航向角
    float heading;          // 原始航向角 (0~360°)
    float heading_filtered; // 互补滤波后的航向角
    
    // 磁干扰检测
    float mag_strength;     // 磁场强度 (Gauss)
    uint8_t interference_detected;  // 干扰标志 (1=干扰)
    
    // 状态标志
    uint8_t data_ready;     // 数据就绪
    uint8_t initialized;    // 初始化完成
    uint32_t last_update;   // 最后更新时间戳
} QMC5883L_t;
```

**全局变量**:
```c
extern volatile QMC5883L_t QMC_Data;
extern volatile QMC5883L_Calibration_t QMC_Calibration;
```

**函数接口**:
```c
uint8_t QMC5883L_Init(I2C_HandleTypeDef *hi2c);
uint8_t QMC5883L_ReadRaw(I2C_HandleTypeDef *hi2c);
float QMC5883L_CalculateHeading(Mahony_TypeDef *mahony);
void QMC5883L_Calibrate(void);
uint8_t QMC5883L_CalibrateUpdate(void);
void QMC5883L_ApplyCalibration(void);

// v1.2.0 新增: 电流补偿接口
void QMC5883L_CompensateCurrent(float throttle);
void QMC5883L_SetCurrentCompensation(float kx, float ky, float kz);
```

**电流补偿说明** (v1.2.0 新增):
- 公式: `Mag_corrected = Mag_raw - Throttle × K`
- 用于补偿电机电流产生的磁场干扰
- 标定方法: 飞机静止，记录不同油门下的磁场读数，计算 K 系数

---

### 2.7 气压计 SPL06

**定义位置**: [`spl06.h:77`](../FLYAMASTER/Core/Inc/spl06.h:77)

```c
typedef struct {
    // 校准系数 (从芯片读取)
    int16_t c0, c1;
    int32_t c00, c10;
    int16_t c01, c11, c20, c21, c30;
    
    // 测量结果
    float pressure;         // 气压 (Pa)
    float temperature;      // 温度 (°C)
    float altitude;         // 海拔高度 (m)
    
    // 参考值 (用于相对高度计算)
    float pressure_ref;     // 参考气压 (上电时的气压)
    float altitude_ref;     // 参考高度 (设为 0)
    
    // 状态标志
    uint8_t initialized;    // 初始化完成标志
    uint8_t data_ready;     // 数据就绪标志
    uint32_t last_update;   // 最后更新时间 (ms)
} SPL06_TypeDef;
```

**全局变量**:
```c
extern volatile SPL06_TypeDef SPL06_Data; // Risk #066: 添加 volatile
```

**函数接口**:
```c
uint8_t SPL06_Init(I2C_HandleTypeDef *hi2c);
uint8_t SPL06_ReadRawData(I2C_HandleTypeDef *hi2c);
float SPL06_PressureToAltitude(float pressure, float pressure_ref);
float SPL06_GetAltitude(volatile SPL06_TypeDef *spl06);
void SPL06_SetReference(volatile SPL06_TypeDef *spl06);
```

---

### 2.8 Flash 参数管理

**定义位置**: [`flash_params.h:70`](../FLYAMASTER/Core/Inc/flash_params.h:70)

```c
typedef struct __attribute__((packed)) {
    // Header (16 字节)
    uint32_t magic;       // 魔数: 0x464C4159 ("FLAY")
    uint16_t version;     // 版本号 (用于双缓冲区选择)
    uint16_t crc16;       // CRC16 校验值
    uint32_t total_size;  // 数据总大小 (用于校验)
    uint32_t reserved1;   // 保留
    
    // PID 参数 (120 字节)
    PID_Params_t pid_roll_angle;
    PID_Params_t pid_roll_rate;
    PID_Params_t pid_pitch_angle;
    PID_Params_t pid_pitch_rate;
    PID_Params_t pid_yaw_angle;
    PID_Params_t pid_yaw_rate;
    PID_Params_t pid_pos_x;
    PID_Params_t pid_pos_y;
    PID_Params_t pid_alt_pos;
    PID_Params_t pid_alt_vel;
    
    // 校准数据 (76 字节)
    float gyro_offset[3];
    float accel_offset[3];
    float mag_calib[12];
    float pressure_ref;
    
    // 飞行配置 (24 字节)
    float hover_throttle;
    uint8_t channel_map[16];
    uint8_t flight_mode_memory;
    uint8_t reserved2[7];
    
    // 系统信息 (16 字节)
    uint32_t total_flight_time;
    uint8_t fw_version[4];
    uint32_t save_count;
    uint32_t reserved3;
} FlashParams_t;
```

**全局变量**:
```c
extern FlashParams_t g_flash_params;  // 全局参数实例
extern uint8_t g_params_dirty;        // 参数脏标志 (需要保存)
```

**函数接口**:
```c
uint8_t FlashParams_Init(void);
uint8_t FlashParams_Load(void);
uint8_t FlashParams_Save(void);
void FlashParams_RestoreDefaults(void);
void FlashParams_ApplyToPID(void);
void FlashParams_ReadFromPID(void);
void FlashParams_PeriodicSave(void);
```

---

### 2.9 匿名上位机 V7 协议

**定义位置**: [`ano_v7.h:43`](../FLYAMASTER/Core/Inc/ano_v7.h:43)

```c
// 姿态数据帧 (0x01) - 18字节
typedef struct {
    int16_t roll;      // 横滚角 ×100 (度)
    int16_t pitch;     // 俯仰角 ×100 (度)
    int16_t yaw;       // 航向角 ×100 (度)
    int32_t alt;       // 高度 ×100 (cm)
    int16_t vx;        // X速度 ×100 (m/s)
    int16_t vy;        // Y速度 ×100 (m/s)
    int16_t vz;        // Z速度 ×100 (m/s)
} __attribute__((packed)) AnoV7_Attitude_t;

// GPS数据帧 (0x09) - 22字节
typedef struct {
    int32_t  latitude;   // 纬度 ×10^7 (度)
    int32_t  longitude;  // 经度 ×10^7 (度)
    int32_t  altitude;   // 海拔高度 ×100 (cm, WGS84)
    uint16_t speed;      // 地速 ×100 (cm/s)
    uint16_t course;     // 航向角 ×100 (度, 0-36000)
    uint8_t  satellites; // 可见卫星数量
    uint8_t  fix_type;   // 定位类型 (0=无效, 1=GPS, 2=DGPS)
    uint16_t hdop;       // HDOP ×100 (水平精度因子)
    uint8_t  valid;      // 数据有效标志
    uint8_t  reserved;   // 保留字节(对齐)
} __attribute__((packed)) AnoV7_GPS_t;
```

**函数接口**:
```c
void AnoV7_Init(UART_HandleTypeDef *huart);
void AnoV7_SendAttitude(void);
void AnoV7_SendSensor(void);
void AnoV7_SendMotor(void);
void AnoV7_SendStatus(void);
void AnoV7_SendGPS(void);
void AnoV7_Parse(uint8_t *buf, uint16_t len);
void AnoV7_RegisterPIDCallback(AnoV7_PID_Callback callback);
```

---

### 2.10 滤波器模块

**定义位置**: [`filter.h:7`](../FLYAMASTER/Core/Inc/filter.h:7)

```c
typedef struct {
    float b0, b1, b2;  // 前馈系数
    float a1, a2;      // 反馈系数
    float x1, x2;      // 输入历史
    float y1, y2;      // 输出历史
} LPF2_TypeDef;
```

**函数接口**:
```c
void LPF2_Init(LPF2_TypeDef *lpf, float sample_freq, float cutoff_freq);
float LPF2_Apply(LPF2_TypeDef *lpf, float input);
```

---

### 2.12 RingBuffer 异步日志模块 (v1.2.0 新增)

**定义位置**: [`ring_buffer.h:15`](../FLYAMASTER/Core/Inc/ring_buffer.h:15)

```c
#define RING_BUFFER_SIZE 512  // 缓冲区大小

typedef struct {
    uint8_t buffer[RING_BUFFER_SIZE];
    volatile uint16_t head;      // 写入位置 (生产者)
    volatile uint16_t tail;      // 读取位置 (DMA 消费者)
    volatile uint8_t dma_busy;   // DMA 忙标志
    UART_HandleTypeDef *huart;   // 关联的 UART 句柄
} RingBuffer_t;
```

**函数接口**:
```c
void RingBuffer_Init(UART_HandleTypeDef *huart);
uint16_t RingBuffer_Write(const uint8_t *data, uint16_t len);
void RingBuffer_StartDMA(void);
void RingBuffer_DMA_TxCpltCallback(void);
int Log_Printf(const char *format, ...);  // 非阻塞 printf 替代
```

**使用说明**:
- 替代阻塞式 `printf`，解决 Issue #111 (高频任务中的控制回路抖动)
- 使用 DMA2_Stream7 (USART1_TX) 进行异步传输
- 在 `HAL_UART_TxCpltCallback` 中调用 `RingBuffer_DMA_TxCpltCallback()`

---

### 2.11 OSD 模块 (AT7456E)

**定义位置**: [`at7456e.h:20`](../FLYAMASTER/Core/Inc/at7456e.h:20)

```c
typedef struct {
    uint8_t initialized;      // 初始化完成标志
    uint8_t video_detected;   // 视频信号检测标志
    uint8_t video_standard;   // 视频制式 (1=PAL, 2=NTSC)
    uint32_t last_update;     // 最后更新时间
} OSD_Data_t;
```

**全局变量**:
```c
extern OSD_Data_t OSD_Data;
```

**函数接口**:
```c
uint8_t AT7456E_Init(SPI_HandleTypeDef *hspi);
void AT7456E_Update(void);
void AT7456E_Clear(void);
void AT7456E_WriteString(uint8_t row, uint8_t col, const char *str);
```

---

## 3. 宏定义 (Macro Definitions)

### 3.1 电机控制

**定义位置**: [`motor.h:6`](../FLYAMASTER/Core/Inc/motor.h:6)

```c
#define MOTOR_MIN_PWM 1000
#define MOTOR_MAX_PWM 2000
#define MOTOR_IDLE_PWM 1100 // 怠速 (AirMode)
```

---

### 3.2 光流参数

**定义位置**: [`optical_flow.h:6`](../FLYAMASTER/Core/Inc/optical_flow.h:6)

```c
#define FLOW_SCALE_FACTOR   0.01f    // 缩放系数 (需根据模块校准)
#define FLOW_MIN_HEIGHT     0.05f    // 最小有效高度 5cm
#define FLOW_MAX_HEIGHT     3.0f     // 最大有效高度 3m
#define FLOW_MIN_QUALITY    30       // 最小有效质量
```

---

### 3.3 SBUS 协议

**定义位置**: [`sbus.h:6`](../FLYAMASTER/Core/Inc/sbus.h:6)

```c
#define SBUS_FRAME_SIZE 25
#define SBUS_CHANNEL_NUMBER 16
#define SBUS_MIN_VALUE   172
#define SBUS_MID_VALUE   992
#define SBUS_MAX_VALUE   1811

// 通道映射定义
#define CH_ROLL     0   // 横滚 (Aileron)
#define CH_PITCH    1   // 俯仰 (Elevator)
#define CH_THROTTLE 2   // 油门 (Throttle)
#define CH_YAW      3   // 偏航 (Rudder)
#define CH_ARM      4   // 解锁开关
#define CH_MODE     5   // 飞行模式开关
```

---

### 3.4 GPS 参数

**定义位置**: [`gps.h:7`](../FLYAMASTER/Core/Inc/gps.h:7)

```c
#define GPS_MIN_SATELLITES      4       // 最少卫星数
#define GPS_MAX_HDOP            2.5f    // 最大水平精度因子
#define GPS_TIMEOUT_MS          1000    // GPS 数据超时 (ms)
#define GPS_RX_BUF_SIZE        256      // NMEA 句子长度 <80字符
#define EARTH_RADIUS_M         6378137.0 // 地球半径 (米)
```

---

### 3.5 磁力计参数

**定义位置**: [`qmc5883l.h:8`](../FLYAMASTER/Core/Inc/qmc5883l.h:8)

```c
#define QMC5883L_ADDR       (0x0D << 1)  // 7-bit: 0x0D
#define MAG_DECLINATION     -3.5f        // 磁偏角 (度, 根据当地调整)
```

---

### 3.6 气压计参数

**定义位置**: [`spl06.h:18`](../FLYAMASTER/Core/Inc/spl06.h:18)

```c
#define SPL06_ADDR              (0x76 << 1)  // SDO=GND: 0x76
#define SPL06_ADDR_ALT          (0x77 << 1)  // SDO=VDD: 0x77
#define SPL06_PRODUCT_ID        0x10
```

---

### 3.7 Flash 参数

**定义位置**: [`flash_params.h:113`](../FLYAMASTER/Core/Inc/flash_params.h:113)

```c
#define FLASH_PARAMS_ADDR_A    0x000000  // Block A 地址
#define FLASH_PARAMS_ADDR_B    0x000200  // Block B 地址 (512 字节偏移)
#define FLASH_PARAMS_MAGIC     0x464C4159  // "FLAY"
#define FLASH_PARAMS_VERSION   1           // 当前版本号
#define FLASH_SAVE_DELAY_MS    2000        // 修改后延迟 2 秒保存
```

---

### 3.8 匿名上位机协议

**定义位置**: [`ano_v7.h:20`](../FLYAMASTER/Core/Inc/ano_v7.h:20)

```c
#define ANO_V7_FRAME_HEADER1    0xAA    // 帧头1
#define ANO_V7_FRAME_HEADER2    0xAF    // 帧头2

// 功能字定义
#define ANO_V7_FUNC_ATTITUDE    0x01    // 姿态数据帧 (FC→PC)
#define ANO_V7_FUNC_SENSOR      0x02    // 传感器数据帧 (FC→PC)
#define ANO_V7_FUNC_MOTOR       0x04    // 电机PWM帧 (FC→PC)
#define ANO_V7_FUNC_STATUS      0x05    // 状态数据帧 (FC→PC)
#define ANO_V7_FUNC_GPS         0x09    // GPS数据帧 (FC→PC)
#define ANO_V7_FUNC_PID_READ    0x10    // 读取PID (PC→FC)
#define ANO_V7_FUNC_PID_WRITE   0x11    // 写入PID (PC→FC)
#define ANO_V7_FUNC_PID_DATA    0x12    // PID数据帧 (FC→PC)

// 错误码定义 (v1.2.0 新增, 位掩码格式)
#define ANO_ERROR_NONE          0x0000  // 无错误
#define ANO_ERROR_IMU_FAIL      0x0001  // IMU 初始化/通信失败
#define ANO_ERROR_BARO_FAIL     0x0002  // 气压计初始化/通信失败
#define ANO_ERROR_MAG_FAIL      0x0004  // 磁力计初始化/通信失败
#define ANO_ERROR_GPS_TIMEOUT   0x0008  // GPS 数据超时 (>3s)
#define ANO_ERROR_RC_LOST       0x0010  // 遥控器信号丢失
#define ANO_ERROR_LOW_BATTERY   0x0020  // 电池电压过低 (<10.5V)
#define ANO_ERROR_MOTOR_LOCK    0x0040  // 电机锁定/堵转
#define ANO_ERROR_FLASH_FAIL    0x0080  // Flash 读写失败
#define ANO_ERROR_SENSOR_CALIB  0x0100  // 传感器需要校准
#define ANO_ERROR_ATTITUDE_ERR  0x0200  // 姿态解算异常 (>60°)
#define ANO_ERROR_FAILSAFE      0x0400  // Failsafe 触发
#define ANO_ERROR_ARMING_BLOCK  0x0800  // 解锁被阻止 (安全检查未通过)
```

---

### 3.9 OSD 参数

**定义位置**: [`at7456e.h:10`](../FLYAMASTER/Core/Inc/at7456e.h:10)

```c
#define OSD_MAX_ROWS_PAL    16
#define OSD_MAX_COLS_PAL    30
#define OSD_CHAR_SPACE      0x00
```

---

## 4. 外设句柄命名规范 (Peripheral Handles) - STM32F405RGT6

| 外设 | 句柄名称 | 引脚分配 | 用途 | DMA |
|:---:|:---|:---|:---|:---|
| **USART1** | `huart1` | PA9/PA10 | 树莓派/日志 (921600 baud) | DMA2_Stream7 TX, DMA2_Stream2 RX |
| **USART2** | `huart2` | PA2/PA3 | GPS 模块 (115200 baud) | DMA1_Stream5 RX (Circular) |
| **UART4** | `huart4` | PC10/PC11 | SBUS (100k, Even, 2Stop) + SmartAudio | DMA1_Stream2 RX, DMA1_Stream4 TX |
| **UART5** | `huart5` | PC12/PD2 | 光流模块 / 匿名上位机 (115200 baud) | DMA1_Stream7 TX |
| **I2C1** | `hi2c1` | PB6/PB7 | MPU6050 + SPL06 (400kHz) | DMA1_Stream0 RX, DMA1_Stream6 TX |
| **I2C2** | `hi2c2` | PB10/PB11 | QMC5883L 磁力计 (100kHz) | DMA1_Stream3 RX |
| **SPI1** | `hspi1` | PA5/PA6/PA7 | W25Q128 + AT7456E (10.5MHz) | DMA2_Stream0 RX, DMA2_Stream3 TX |
| **TIM1** | `htim1` | PA8 (CH1) | WS2812 RGB 灯 (PWM) | DMA2_Stream1 |
| **TIM4** | `htim4` | - | HAL 时基 (Timebase Source) | - |
| **TIM8** | `htim8` | PC6-PC9 (CH1-4) | 电机 PWM (400Hz) | - |
| **ADC1** | `hadc1` | PC0 (IN10), PC5 (IN15) | 电池电压+电流 | DMA2_Stream4 (Circular) |
| **USB_OTG_FS** | `hpcd_USB_OTG_FS` | PA11/PA12 | CDC 虚拟串口 | - |
| **GPIO** | `Power_Key` | PA0-WKUP | 软开关按键检测 (Input, Pull-down) | - |
| **GPIO** | `Power_Hold` | PC1 | 电源锁存控制 (Output) | - |
| **GPIO** | `BUZZER` | PC2 | 蜂鸣器 (Output) | - |
| **GPIO** | `LED_BLUE` | PC3 | 蓝色 LED (Output) | - |
| **GPIO** | `LED_RED` | PC4 | 红色 LED (Output) | - |
| **GPIO** | `USB_DETECT` | PB9 | USB 插入检测 (Input, Pull-down) | - |
| **GPIO** | `FLASH_CS` | PA4 | Flash 片选 (Output, High) | - |
| **GPIO** | `OSD_CS` | PB12 | OSD 片选 (Output, High) | - |

**规则**:
- **严禁臆造外设句柄**! 例如文档里只定义了 `huart4`,代码里不能写 `huart6`
- 如需新增外设,必须先更新 [`08_hardware_design.md`](08_hardware_design.md)
- **注意**: F405 没有 UART6，GPS 使用 USART2，SBUS 使用 UART4

---

## 5. 函数命名规范 (Function Naming)

| 模块 | 命名格式 | 示例 |
|:---:|:---|:---|
| 初始化函数 | `Module_Init()` | `GPS_Init()`, `QMC5883L_Init()` |
| 数据读取 | `Module_Read*()` | `SPL06_ReadRawData()`, `QMC5883L_ReadRaw()` |
| 数据解析 | `Module_Parse()` | `GPS_Parse_NMEA()`, `SBUS_Parse()` |
| 数据获取 | `Module_Get*()` | `SBUS_GetThrottle()`, `Flow_GetVelocity()` |
| 校准函数 | `Module_Calibrate()` | `QMC5883L_Calibrate()`, `SPL06_SetReference()` |
| 计算函数 | `Module_Calculate*()` | `QMC5883L_CalculateHeading()`, `PID_Calculate()` |
| 发送函数 | `Module_Send*()` | `AnoV7_SendAttitude()`, `AnoV7_SendGPS()` |

---

### 2.13 调试工具模块 (v1.2.0 新增)

**定义位置**: [`debug_tools.h:15`](../FLYAMASTER/Core/Inc/debug_tools.h:15)

```c
// I2C 扫描结果结构体
typedef struct {
    uint8_t found_count;        // 发现的设备数量
    uint8_t addresses[16];      // 发现的设备地址 (最多 16 个)
} I2C_ScanResult_t;

// 磁力计电流补偿标定状态
typedef enum {
    MAG_CALIB_IDLE = 0,         // 空闲状态
    MAG_CALIB_COLLECTING_LOW,   // 采集低油门数据
    MAG_CALIB_COLLECTING_HIGH,  // 采集高油门数据
    MAG_CALIB_CALCULATING,      // 计算补偿系数
    MAG_CALIB_DONE              // 标定完成
} MagCalibState_t;

// 磁力计电流补偿标定数据
typedef struct {
    MagCalibState_t state;      // 当前状态
    float mag_x_low, mag_y_low, mag_z_low;   // 低油门采样
    float mag_x_high, mag_y_high, mag_z_high; // 高油门采样
    float throttle_low, throttle_high;        // 油门值
    uint16_t sample_count_low, sample_count_high;
    float k_x, k_y, k_z;        // 计算得到的补偿系数
    uint8_t valid;              // 标定结果有效标志
} MagCurrentCalib_t;
```

**全局变量**:
```c
extern MagCurrentCalib_t g_mag_current_calib;
```

**函数接口**:
```c
// I2C 总线扫描
uint8_t I2C_ScanBus(I2C_HandleTypeDef *hi2c, I2C_ScanResult_t *result);
void I2C_PrintScanResult(I2C_ScanResult_t *result);
void I2C_ScanAllBuses(void);

// 磁力计电流补偿标定
void MagCurrentCalib_Start(void);
void MagCurrentCalib_Update(float mag_x, float mag_y, float mag_z, float throttle);
MagCalibState_t MagCurrentCalib_GetState(void);
void MagCurrentCalib_PrintResult(void);
```

**使用说明**:
- **I2C 扫描**: 在 `main()` 初始化后调用 `I2C_ScanAllBuses()` 检测总线设备
- **磁力计标定**:
  1. 卸下螺旋桨！
  2. 调用 `MagCurrentCalib_Start()` 开始标定
  3. 保持低油门 (<5%) 等待采集完成
  4. 缓慢增加油门到 >70% 等待采集完成
  5. 系统自动计算 K 系数并打印结果

---

## 6. 更新日志 (Update Log)

| 日期 | 变更内容 | 责任人 |
|:---:|:---|:---|
| 2026-01-16 | 创建接口定义文档 | Doro |
| 2026-01-16 | 添加 GPS 模块接口 | Doro |
| 2026-01-16 | 添加 QMC5883L 磁力计接口 | Doro |
| 2026-01-16 | 添加 Flash 参数管理接口 | Doro |
| 2026-01-16 | 添加匿名上位机 V7 协议接口 | Doro |
| 2026-01-18 | 添加 RingBuffer 异步日志模块 | Doro |
| 2026-01-18 | 添加 QMC5883L 电流补偿接口 | Doro |
| 2026-01-18 | 更新 Motor_Mix Airmode 算法说明 | Doro |
| 2026-01-18 | 更新 PID Anti-windup 算法说明 | Doro |
| 2026-01-18 | 添加调试工具模块 (I2C 扫描 + 磁力计标定) | Doro |
| 2026-01-18 | 添加 AnoV7 错误码定义 (12 个错误码) | Doro |
| 2026-01-23 | 添加 USB_DETECT 引脚定义 (PB9) | Doro |

---

## 7. 冲突检查清单 (Conflict Checklist)

在创建新变量/函数前,必须检查:

- [ ] 是否已在本文档中定义过?
- [ ] 命名是否符合项目规范? (前缀、语义)
- [ ] 是否需要 `volatile` 修饰? (RTOS/ISR 共享)
- [ ] 是否需要 `extern` 声明? (跨文件访问)
- [ ] 是否需要 `__attribute__((packed))`? (网络协议/Flash存储)
- [ ] 是否需要更新 `pinout_allocation.md` 或 `cubemx_setup_guide.md`?

---

**使用规范**:
1. 每次编写代码前,**必须**先查阅此文档
2. 如果发现文档中没有你需要的接口,**必须**先更新此文档再写代码
3. 修改结构体定义时,**必须**同步更新 [`algorithm_definition.md`](algorithm_definition.md)
4. 发现重复定义时,立即报告并在 [`issues_and_feedback.md`](issues_and_feedback.md) 中记录

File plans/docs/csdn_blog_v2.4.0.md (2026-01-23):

# FLYAMASTER 开源飞控 v2.4.0 硬件设计完成 - 从 STM32F405 到专业级飞行仪表盘

> **项目状态**: 硬件设计完成，等待 PCB 打样验证
> **版本**: HW v2.4.0 / FW v2.3.0
> **日期**: 2026-01-23

---

## 📋 目录

1. [项目简介](#1-项目简介)
2. [硬件架构总览](#2-硬件架构总览)
3. [核心功能亮点](#3-核心功能亮点)
4. [电源管理设计](#4-电源管理设计)
5. [PCB 布局约束](#5-pcb-布局约束)
6. [下一步计划](#6-下一步计划)

---

## 1. 项目简介

FLYAMASTER 是一款基于 **STM32F405RGT6** 的开源四轴飞控项目，采用 **FreeRTOS** 实时操作系统，支持多种飞行模式（自稳/定高/定点/返航）。

### 技术栈

| 类别 | 技术选型 |
|:---|:---|
| **MCU** | STM32F405RGT6 (168MHz, 1MB Flash, 192KB RAM) |
| **RTOS** | FreeRTOS CMSIS_V2 |
| **IMU** | MPU6050 (6轴) |
| **气压计** | SPL06-001 |
| **磁力计** | QMC5883L |
| **接收机** | ELRS (CRSF 协议) |
| **OSD** | AT7456E |
| **Flash** | W25Q128 (16MB) |

---

## 2. 硬件架构总览

### 2.1 MCU 选型对比

| 参数 | STM32F407VET6 (旧) | STM32F405RGT6 (新) |
|:---|:---|:---|
| 封装 | LQFP-100 | **LQFP-64** |
| Flash | 512KB | **1MB** |
| GPIO | 82 | **51** |
| 价格 | ~¥35 | **~¥25** |

**选型理由**: F405 封装更小、Flash 更大、价格更低，非常适合小型飞控。

### 2.2 引脚分配总览

```
┌─────────────────────────────────────────────────────────────┐
│                    STM32F405RGT6 引脚分配                    │
├─────────────────────────────────────────────────────────────┤
│ 传感器 (I2C1)                                               │
│   PB6/PB7: MPU6050 + SPL06 + QMC5883L (400kHz)             │
│   PB5: MPU_INT (数据就绪中断)                               │
├─────────────────────────────────────────────────────────────┤
│ 通信接口                                                    │
│   USART1 (PA9/PA10): K210 上位机 / 日志 (921600 baud)      │
│   USART2 (PA2/PA3): GPS 模块 (115200 baud)                 │
│   USART3 (PB10/PB11): ELRS 接收机 (CRSF, 420000 baud)      │
│   UART4 (PC10/PC11): SmartAudio VTX (4800 baud)            │
│   UART5 (PC12/PD2): 光流模块 (115200 baud)                 │
├─────────────────────────────────────────────────────────────┤
│ 电机 PWM (TIM8, 400Hz)                                      │
│   PC6-PC9: MOTOR_1 ~ MOTOR_4                                │
├─────────────────────────────────────────────────────────────┤
│ LED 指示灯 (7 颗)                                           │
│   PC3: LED_SYS (蓝) | PC4: LED_ERR (红)                    │
│   PB0: LED_GPS (绿) | PB1: LED_RX (黄)                     │
│   PB13: LED_MODE (白) | PB14: LED_LOG (橙) | PB15: LED_VTX (青) │
├─────────────────────────────────────────────────────────────┤
│ 其他                                                        │
│   PA8: WS2812 RGB 灯 (TIM1_CH1)                            │
│   PA11/PA12: USB CDC                                        │
│   PB9: USB_DETECT (插入检测)                                │
│   PC0/PC5: 电池电压/电流检测 (ADC)                          │
└─────────────────────────────────────────────────────────────┘
```

---

## 3. 核心功能亮点

### 3.1 CRSF/ELRS 接收机支持 (HW v2.2.0)

**为什么选择 CRSF 协议？**

| 特性 | SBUS | CRSF |
|:---|:---|:---|
| 波特率 | 100kbps | **420kbps** |
| 通信方向 | 单向 | **双向 (支持遥测)** |
| 反相器 | 需要 | **不需要** |
| 校验 | 无 | **CRC8** |

**硬件连接**:
- USART3 (PB10/PB11) 专用于 ELRS 接收机
- DMA1_Stream1 循环接收，Very High 优先级
- 支持遥测回传（电池电压、RSSI、GPS 等）

### 3.2 7 颗 LED 专业级飞行仪表盘 (HW v2.3.0)

> **设计理念**: 一眼即可判断飞控状态

#### 功能分组

| 组别 | 引脚 | 颜色 | 功能 |
|:---|:---|:---|:---|
| **核心系统** | PC3 | 蓝色 | 系统心跳 (1Hz 闪烁=待机, 常亮=已解锁) |
| | PC4 | 红色 | 警告/错误 (慢闪=低电压, 快闪=传感器故障) |
| **导航链路** | PB0 | 绿色 | GPS 状态 (闪烁=搜星, 常亮=3D Fix) |
| | PB1 | 黄色 | 遥控接收 (常亮=正常, 闪烁=RSSI低, 灭=Failsafe) |
| **飞行任务** | PB13 | 白色 | 飞行模式 (灭=自稳, 亮=手动, 闪=返航) |
| | PB14 | 橙色 | 黑匣子 (闪烁=正在写入Flash) |
| | PB15 | 青色 | 图传状态 (亮=PIT Mode) |

#### 电路设计

采用**灌电流接法** (Sink Mode)，低电平点亮：

```
3.3V ──> 限流电阻 ──> LED (+) ──> LED (-) ──> MCU 引脚
```

- 红/黄/橙色 LED: 1kΩ 限流电阻
- 蓝/绿/白/青色 LED: 470-680Ω 限流电阻

### 3.3 USB 插入检测 (HW v2.4.0)

**问题**: 电池供电时，5V 会通过 USB 反灌到电脑，导致 MCU 误判 USB 已连接。

**解决方案**: 从肖特基二极管阳极取信号

```
USB VBUS ──> D3 (SS14) 阳极 ──┬──> D3 阴极 ──> +5V_USB
                              │
                              └──[R: 10kΩ]──> PB9 (USB_DETECT)
```

- PB9 配置为 GPIO Input, Pull-down
- USB 插入时 PB9 为高电平，电池供电时为低电平

---

## 4. 电源管理设计

### 4.1 电源架构

```
电池 (2S-9S, 4.5-40V)
    │
    ├──> DCDC SY8303 ──> 5V/3A ──> LDO RT9193 ──> 3.3V/500mA
    │                      │
    │                      ├──> USB 5V (带反灌保护)
    │                      ├──> 蜂鸣器
    │                      └──> 外设接口
    │
    ├──> 电机 (直接电池供电)
    ├──> 图传 VTX (VBAT)
    └──> ADC 电压检测 (分压 1:11)
```

### 4.2 关键元件

| 类型 | 规格 | 用途 |
|:---|:---|:---|
| DCDC | SY8303 (SOT-23-6) | 5V/3A, 4.5-40V 输入 |
| LDO | RT9193-33 | 3.3V/500mA |
| 肖特基 | SS14 (SMA) | USB 反灌保护 |

---

## 5. PCB 布局约束

### 5.1 传感器隔离

- **磁力计 (QMC5883L)**: 必须远离电机线、大电流回路
- **气压计 (SPL06)**: 避免强光直射和气流直吹

### 5.2 走线规范

| 类型 | 线宽 |
|:---|:---|
| 主电源 (VBAT) | > 30mil |
| 3.3V / 5V | > 20mil |
| 信号线 | 6-8mil |
| USB 差分线 | 90Ω 阻抗控制 |

### 5.3 晶振处理

- 晶振下方**禁止走线**
- 晶振外壳接地
- 负载电容靠近晶振引脚

---

## 6. 下一步计划

- [ ] PCB 打样 (嘉立创)
- [ ] 焊接验证
- [ ] 固件调试
- [ ] 首飞测试

---

## 📎 相关链接

- **GitHub**: [待添加]
- **硬件设计文档**: `08_hardware_design.md`
- **版本日志**: `05_changelog.md`

---

## 📝 Git 提交信息参考

```bash
git add .
git commit -m "feat(hw): FLYAMASTER v2.4.0 硬件设计完成

## 硬件变更 (HW v2.2.0 - v2.4.0)

### HW v2.4.0 - USB Detection Enhancement
- 新增 USB 插入检测引脚 (PB9)
- 从 D3 肖特基二极管阳极取信号
- 解决 USB 反灌误判问题

### HW v2.3.0 - 7-LED Professional Indicator System
- 新增 7 颗状态指示 LED
- 采用灌电流接法 (Sink Mode)

### HW v2.2.0 - UART Refactor & I2C Consolidation
- USART3 用于 ELRS 接收机 (CRSF 协议)
- UART4 专用于 SmartAudio VTX 控制
- 移除 I2C2，所有传感器使用 I2C1

## 固件变更 (FW v2.2.0 - v2.3.0)

### FW v2.3.0 - LED Indicator System
- 新增 led_indicator.c/h 驱动

### FW v2.2.0 - CRSF/ELRS Receiver
- 新增 crsf.c/h 驱动
- 420000 baud, 双向通信

状态: 硬件设计完成，等待 PCB 验证"
```

---

**作者**: Doro  
**日期**: 2026-01-23  
**标签**: STM32, 飞控, 开源硬件, ELRS, CRSF

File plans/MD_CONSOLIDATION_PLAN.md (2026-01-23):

# 📋 FLYAMASTER 文档整合计划 (MD Consolidation Plan)

**创建时间**: 2026-01-22
**状态**: 待审批
**目标**: 将分散在 `plans/` 和 `plans/docs/` 两个目录的 23 个 MD 文件整合为 9 个核心文档

---

## 1. 当前文件分布分析

### 1.1 plans/ 根目录 (9 个文件)

| 文件名 | 大小 | 内容摘要 | 处理方式 |
|---|---|---|---|
| `03_issue_tracker.md` | 19KB | 25个问题追踪 | **保留为主版本** |
| `04_algo_design.md` | 11KB | Mahony/PID/混控算法 | **保留为主版本** |
| `05_changelog.md` | 19KB | FW v1.0.0 ~ v2.1.5 | **保留为主版本** |
| `05_History_Log.md` | 6KB | 早期开发历史归档 | 合并到 05_changelog.md |
| `07_research_and_ideas.md` | 7KB | EKF分析/芯片评估 | **保留为主版本** |
| `08_hardware_design.md` | 27KB | 完整引脚分配/DMA配置 | **保留为主版本** |
| `development_progress_log.md` | 5KB | 开发进度日志 | 合并到 05_changelog.md |
| `interface_definition.md` | 25KB | 结构体/函数/宏定义 | **重命名为 01_definitions.md** |
| `issues_and_feedback.md` | 26KB | Bug/Risk/Feedback | 合并到 03_issue_tracker.md |

### 1.2 plans/docs/ 子目录 (14 个文件)

| 文件名 | 大小 | 内容摘要 | 处理方式 |
|---|---|---|---|
| `01_Project_Master_Plan.md` | 2KB | 项目愿景/里程碑 | 提取到 02_project_roadmap.md |
| `02_Hardware_Architecture.md` | 2KB | 旧版硬件架构 (F407) | **废弃** → 已被 08 替代 |
| `02_Schematic_Design_Guide.md` | 7KB | 原理图设计指南 | 合并到 08_hardware_design.md |
| `04_Module_Drivers_Deep_Dive.md` | 2KB | 驱动模块说明 | 合并到 01_definitions.md |
| `05_changelog.md` | 2KB | 旧版变更日志 | **废弃** → 已被根目录版本替代 |
| `05_History_Log.md` | 6KB | 开发历史归档 | **废弃** → 与根目录重复 |
| `07_research_and_ideas.md` | 7KB | 调研分析 | **废弃** → 与根目录重复 |
| `08_Physics_and_Safety_Upgrade.md` | 5KB | 物理安全强化方案 | 合并到 08_hardware_design.md |
| `09_Critical_Safety_Patch_Plan.md` | 3KB | 关键安全补丁计划 | 合并到 03_issue_tracker.md |
| `csdn_blog_outline.md` | 2KB | CSDN博客大纲 | **废弃** → 非核心文档 |
| `development_progress_log.md` | 2KB | 开发进度日志 | **废弃** → 与根目录重复 |
| `FLYAMASTER_v2.0_Whitepaper.md` | 12KB | 项目架构白皮书 | 提取到 06_operation_guide.md |
| `interface_definition.md` | 25KB | 接口定义 | **废弃** → 与根目录重复 |
| `issues_and_feedback.md` | 12KB | 问题反馈 | **废弃** → 与根目录重复 |

---

## 2. 整合后的目标结构

```
plans/
├── README.md                    # [新建] 项目总览与索引
├── 01_definitions.md            # [重命名] 命名规范与接口定义
├── 02_project_roadmap.md        # [新建] 项目路线图
├── 03_issue_tracker.md          # [整合] 问题追踪日志
├── 04_algo_design.md            # [保留] 算法设计
├── 05_changelog.md              # [整合] 版本更新日志
├── 06_operation_guide.md        # [新建] 操作指南
├── 07_research_and_ideas.md     # [保留] 调研分析
├── 08_hardware_design.md        # [整合] 硬件设计
├── archive/                     # [新建] 废弃文档归档
│   ├── 02_Hardware_Architecture.md.deprecated
│   ├── csdn_blog_outline.md.deprecated
│   └── ...
└── .kilocode/                   # 规则配置
    └── rules/
        └── rules.md
```

---

## 3. 详细整合方案

### 3.1 README.md (新建)

**来源**: 从 `01_Project_Master_Plan.md` 和 `FLYAMASTER_v2.0_Whitepaper.md` 提取

**内容结构**:
```markdown
# 🚁 FLYAMASTER 飞控项目

## 项目简介
## 技术栈 (MCU/RTOS/EDA)
## 文档索引 (链接到 01-08)
## 快速开始
```

---

### 3.2 01_definitions.md (重命名 + 合并)

**主版本**: `plans/interface_definition.md` (772行, 25KB)
**合并来源**: `docs/04_Module_Drivers_Deep_Dive.md` (驱动模块说明)

**处理方式**:
1. 将 `interface_definition.md` 重命名为 `01_definitions.md`
2. 将 `04_Module_Drivers_Deep_Dive.md` 中的驱动配置信息合并到相应章节

---

### 3.3 02_project_roadmap.md (新建)

**来源**: 从 `01_Project_Master_Plan.md` 提取里程碑和待办事项

**内容结构**:
```markdown
# 📅 项目路线图

## ✅ Phase 1: 基础飞行 [已完成]
## ✅ Phase 2: 进阶功能 [已完成]
## 🚧 Phase 3: 智能化与优化 [进行中]
- [ ] EKF 状态估计
- [ ] 航点飞行
- [ ] 视觉避障
- [ ] 自动返航
## 📋 Phase 4: 硬件设计 [待开始]
- [ ] 原理图设计
- [ ] PCB 布局
- [ ] 打样验证
```

---

### 3.4 03_issue_tracker.md (整合)

**主版本**: `plans/03_issue_tracker.md` (644行, 19KB)
**合并来源**:
- `plans/issues_and_feedback.md` (591行, 26KB)
- `docs/issues_and_feedback.md` (288行, 12KB) - 旧版本
- `docs/09_Critical_Safety_Patch_Plan.md` (54行, 3KB)

**处理方式**:
1. 保留主版本的所有内容
2. 从 `issues_and_feedback.md` 提取未记录的 Issue/Risk
3. 将 `09_Critical_Safety_Patch_Plan.md` 的安全补丁计划转为 Issue 条目

---

### 3.5 04_algo_design.md (保留)

**主版本**: `plans/04_algo_design.md` (415行, 11KB)

**处理方式**: 无需修改，已是最新版本

---

### 3.6 05_changelog.md (整合)

**主版本**: `plans/05_changelog.md` (434行, 19KB)
**合并来源**:
- `plans/05_History_Log.md` (118行, 6KB)
- `plans/development_progress_log.md` (95行, 5KB)
- `docs/05_changelog.md` (35行, 2KB) - 旧版本
- `docs/05_History_Log.md` (118行, 6KB) - 重复
- `docs/development_progress_log.md` (25行, 2KB) - 旧版本

**处理方式**:
1. 保留主版本的所有内容
2. 将 `05_History_Log.md` 的早期开发历史添加到 "归档" 章节
3. 将 `development_progress_log.md` 的进度日志按日期合并

---

### 3.7 06_operation_guide.md (新建)

**来源**: 从 `FLYAMASTER_v2.0_Whitepaper.md` 提取

**内容结构**:
```markdown
# 📖 操作指南

## 1. 开发环境搭建
- Keil MDK 配置
- CubeMX 配置
- VSCode 配置

## 2. 编译与烧录
- 编译步骤
- 烧录方法 (SWD/DFU)

## 3. 调试工具
- 匿名上位机 V7
- USB 虚拟串口

## 4. 飞行操作
- 解锁/上锁
- 飞行模式切换
- 失控保护
```

---

### 3.8 07_research_and_ideas.md (保留)

**主版本**: `plans/07_research_and_ideas.md` (120行, 7KB)

**处理方式**: 无需修改，已是最新版本
- `docs/07_research_and_ideas.md` 与根目录版本完全相同，直接删除

---

### 3.9 08_hardware_design.md (整合)

**主版本**: `plans/08_hardware_design.md` (635行, 27KB)
**合并来源**:
- `docs/02_Schematic_Design_Guide.md` (150行, 7KB) - 原理图设计指南
- `docs/08_Physics_and_Safety_Upgrade.md` (103行, 5KB) - 物理安全强化

**处理方式**:
1. 保留主版本的所有内容
2. 将 `02_Schematic_Design_Guide.md` 的原理图设计指南添加为新章节
3. 将 `08_Physics_and_Safety_Upgrade.md` 的安全强化方案添加为新章节

---

## 4. 废弃文件处理

### 4.1 废弃标记格式

对于废弃的内容，使用以下格式标记：

```markdown
> ⚠️ **[DEPRECATED]** 废弃于: 2026-01-22
> - **废弃原因**: [原因说明]
> - **替代方案**: [新文档/新章节的链接]
> - **原始文件**: [原文件路径]
```

### 4.2 废弃文件列表

| 原文件 | 废弃原因 | 替代方案 |
|---|---|---|
| `docs/02_Hardware_Architecture.md` | 基于旧版 F407，已迁移到 F405 | `08_hardware_design.md` |
| `docs/05_changelog.md` | 内容已合并到根目录版本 | `05_changelog.md` |
| `docs/05_History_Log.md` | 与根目录版本重复 | `05_changelog.md` |
| `docs/07_research_and_ideas.md` | 与根目录版本重复 | `07_research_and_ideas.md` |
| `docs/development_progress_log.md` | 内容已合并 | `05_changelog.md` |
| `docs/interface_definition.md` | 与根目录版本重复 | `01_definitions.md` |
| `docs/issues_and_feedback.md` | 内容已合并 | `03_issue_tracker.md` |
| `docs/csdn_blog_outline.md` | 非核心文档，仅供参考 | 移至 `archive/` |

---

## 5. 整合流程图

```mermaid
flowchart TD
    subgraph 源文件
        A1[plans/interface_definition.md]
        A2[plans/03_issue_tracker.md]
        A3[plans/04_algo_design.md]
        A4[plans/05_changelog.md]
        A5[plans/07_research_and_ideas.md]
        A6[plans/08_hardware_design.md]
        A7[plans/issues_and_feedback.md]
        A8[plans/05_History_Log.md]
        A9[plans/development_progress_log.md]
        
        B1[docs/01_Project_Master_Plan.md]
        B2[docs/02_Schematic_Design_Guide.md]
        B3[docs/04_Module_Drivers_Deep_Dive.md]
        B4[docs/08_Physics_and_Safety_Upgrade.md]
        B5[docs/09_Critical_Safety_Patch_Plan.md]
        B6[docs/FLYAMASTER_v2.0_Whitepaper.md]
    end
    
    subgraph 目标文件
        C0[README.md]
        C1[01_definitions.md]
        C2[02_project_roadmap.md]
        C3[03_issue_tracker.md]
        C4[04_algo_design.md]
        C5[05_changelog.md]
        C6[06_operation_guide.md]
        C7[07_research_and_ideas.md]
        C8[08_hardware_design.md]
    end
    
    B1 --> C0
    B6 --> C0
    
    A1 --> C1
    B3 --> C1
    
    B1 --> C2
    
    A2 --> C3
    A7 --> C3
    B5 --> C3
    
    A3 --> C4
    
    A4 --> C5
    A8 --> C5
    A9 --> C5
    
    B6 --> C6
    
    A5 --> C7
    
    A6 --> C8
    B2 --> C8
    B4 --> C8
```

---

## 6. 执行步骤

### Step 1: 创建目录结构
- [ ] 创建 `plans/archive/` 目录

### Step 2: 创建新文件
- [ ] 创建 `README.md`
- [ ] 创建 `02_project_roadmap.md`
- [ ] 创建 `06_operation_guide.md`

### Step 3: 重命名文件
- [ ] `interface_definition.md` → `01_definitions.md`

### Step 4: 整合内容
- [ ] 整合 `01_definitions.md` (合并驱动模块说明)
- [ ] 整合 `03_issue_tracker.md` (合并 issues_and_feedback + 安全补丁)
- [ ] 整合 `05_changelog.md` (合并历史日志 + 进度日志)
- [ ] 整合 `08_hardware_design.md` (合并原理图指南 + 安全强化)

### Step 5: 处理废弃文件
- [ ] 将废弃文件移至 `archive/` 并添加 `.deprecated` 后缀
- [ ] 在废弃文件开头添加废弃标记

### Step 6: 更新配置
- [ ] 更新 `.kilocode/rules/rules.md` 中的路径配置

### Step 7: 清理
- [ ] 删除 `plans/docs/` 目录 (所有内容已整合或归档)

---

## 7. 确认事项

请确认以下问题：

1. **废弃文件处理方式**: 
   - 方案 A: 移至 `archive/` 目录保留
   - 方案 B: 直接删除 (内容已整合)
   - **推荐**: 方案 A (保留历史记录)

2. **docs/ 目录处理**:
   - 整合完成后是否删除 `docs/` 子目录？
   - **推荐**: 删除，所有内容统一放在 `plans/` 根目录

3. **是否需要保留 CSDN 博客大纲**:
   - 这是非核心文档，但可能对后续写博客有参考价值
   - **推荐**: 移至 `archive/` 保留

---

**请审阅此计划，如有修改意见请告知。确认后我将切换到 Code 模式执行整合操作。**

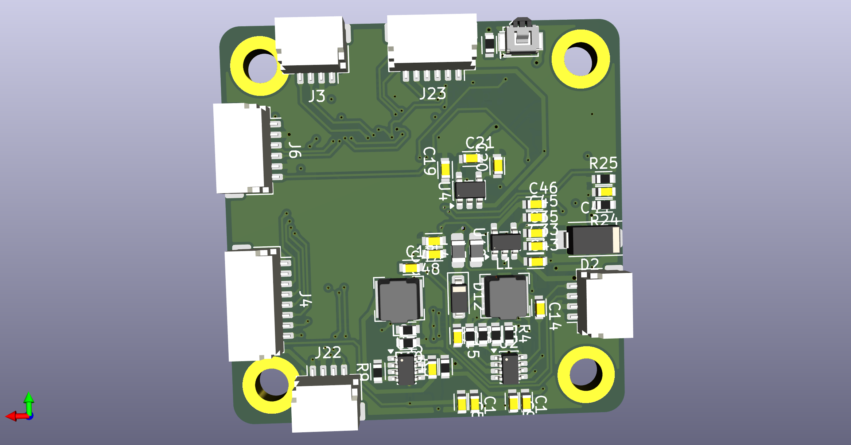
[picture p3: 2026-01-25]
Hardware/zero star/zero star2.png

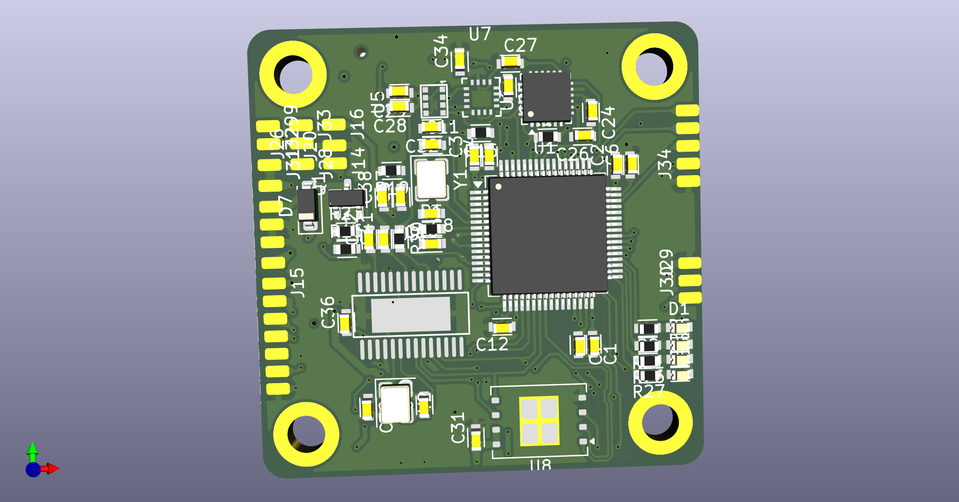
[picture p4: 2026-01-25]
Hardware/zero star/zero star.png

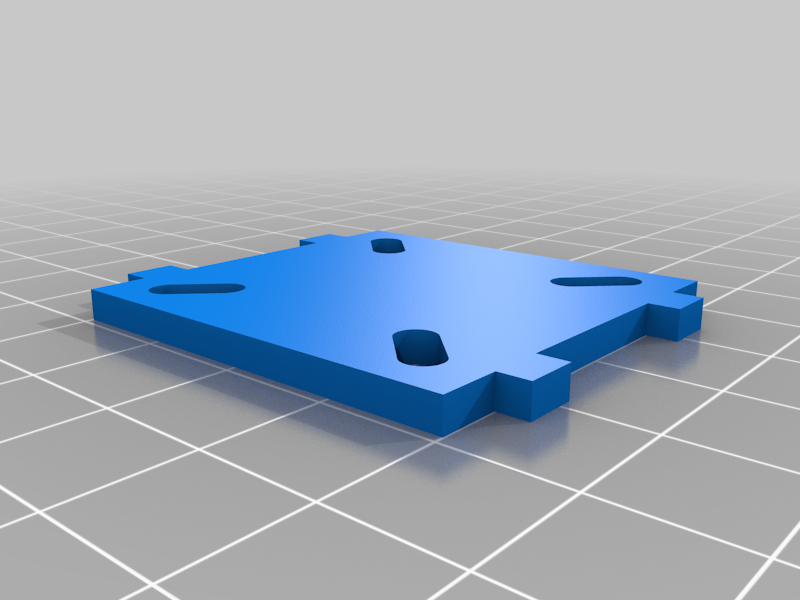
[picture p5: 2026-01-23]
3D/images/Peon230_FPVcam_v1.png

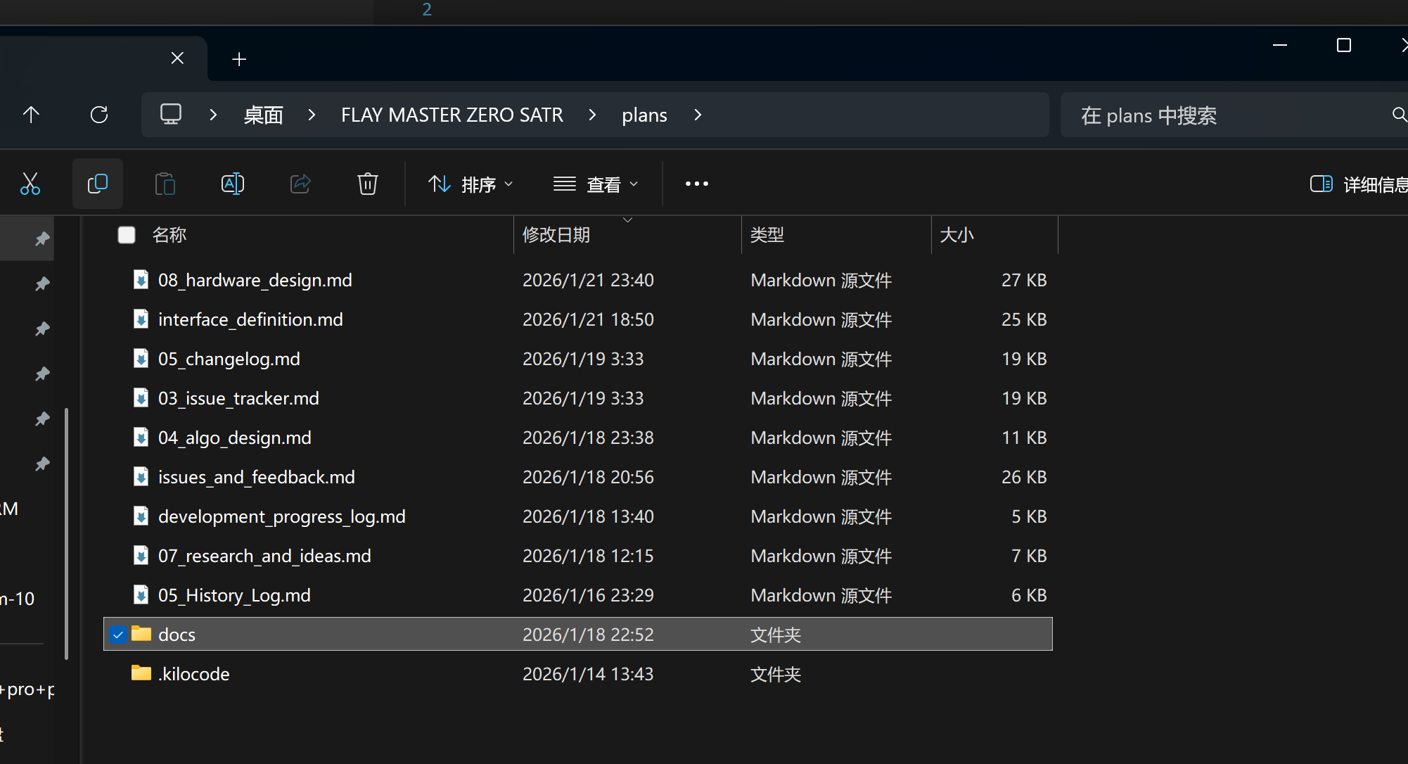
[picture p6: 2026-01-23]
plans/docs/image.png

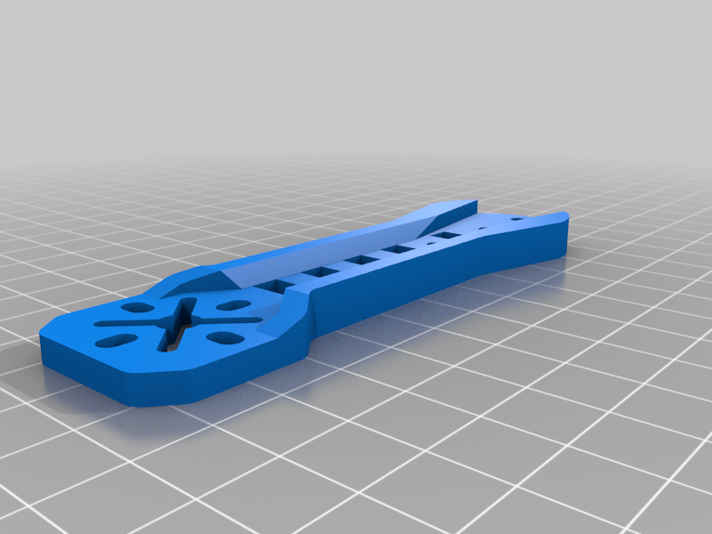
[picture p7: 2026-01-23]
3D/images/Peon230_Arm_v1.png

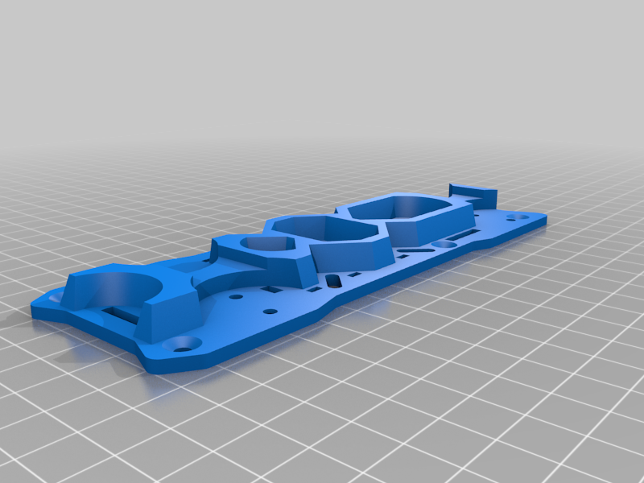
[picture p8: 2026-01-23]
3D/images/Peon230_Base_v1.1.png

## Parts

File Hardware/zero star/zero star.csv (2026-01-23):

Reference | Qty | Value | DNP | Exclude from BOM | Exclude from Board | Footprint | Datasheet
BZ+1,J2,J7,J8,J9,J10,J11,J12,J13,J14,J15,J16,J17,J18,J19,J20,J21,J24,J25,J26,J27,J28,J29,J30,J31,J32,J33,J299 | 28 | Conn_01x01 |  |  |  | TestPoint:TestPoint_Pad_2.0x2.0mm | ~
C1,C2,C3,C4,C12,C13,C14,C16,C17 | 9 | 100nf |  |  |  | PCM_fab:C_0603 | https://www.yageo.com/upload/media/product/productsearch/datasheet/mlcc/UPY-GP_NP0_16V-to-50V_18.pdf
C5,C9,C15,C18,C21,C46 | 6 | 22uF |  |  |  | PCM_fab:C_0603 | https://www.yageo.com/upload/media/product/productsearch/datasheet/mlcc/UPY-GP_NP0_16V-to-50V_18.pdf
C6,C7 | 2 | 2.2uF |  |  |  | PCM_fab:C_0603 | https://www.yageo.com/upload/media/product/productsearch/datasheet/mlcc/UPY-GP_NP0_16V-to-50V_18.pdf
C8,C24,C26,C27,C28,C29,C31,C32,C33,C36,C37,C38,C41,C44,C47 | 15 | 100nF |  |  |  | PCM_fab:C_0603 | https://www.yageo.com/upload/media/product/productsearch/datasheet/mlcc/UPY-GP_NP0_16V-to-50V_18.pdf
C10,C11,C39,C40 | 4 | 22pF |  |  |  | PCM_fab:C_0603 | https://www.yageo.com/upload/media/product/productsearch/datasheet/mlcc/UPY-GP_NP0_16V-to-50V_18.pdf
C19,C43 | 2 | 10uF |  |  |  | PCM_fab:C_0603 | https://www.yageo.com/upload/media/product/productsearch/datasheet/mlcc/UPY-GP_NP0_16V-to-50V_18.pdf
C20,C45 | 2 | 22nF |  |  |  | PCM_fab:C_0603 | https://www.yageo.com/upload/media/product/productsearch/datasheet/mlcc/UPY-GP_NP0_16V-to-50V_18.pdf
C25 | 1 | 2.2nF |  |  |  | PCM_fab:C_0603 | https://www.yageo.com/upload/media/product/productsearch/datasheet/mlcc/UPY-GP_NP0_16V-to-50V_18.pdf
C34 | 1 | 220nF |  |  |  | PCM_fab:C_0603 | https://www.yageo.com/upload/media/product/productsearch/datasheet/mlcc/UPY-GP_NP0_16V-to-50V_18.pdf
C35,C42 | 2 | 47uF |  |  |  | PCM_fab:C_0603 | https://www.yageo.com/upload/media/product/productsearch/datasheet/mlcc/UPY-GP_NP0_16V-to-50V_18.pdf
C48 | 1 | 1uF |  |  |  | PCM_fab:C_0603 | https://www.yageo.com/upload/media/product/productsearch/datasheet/mlcc/UPY-GP_NP0_16V-to-50V_18.pdf
D1,D5,D6,D8,D9,D10,D11 | 7 | LED_0603 |  |  |  | PCM_fab:LED_0603 | https://www.digikey.com/en/products/detail/harvatek-corporation/B1911USD-20D000114U1930/15519991
D2 | 1 | SMAJ33A |  |  |  | Diode_SMD:D_SMA | https://www.littelfuse.com/media?itemid=75e32973-b177-4ee3-a0ff-cedaf1abdb93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
D3 | 1 | SS14 |  |  |  | Diode_SMD:D_SMA | https://www.vishay.com/docs/88746/ss12.pdf
D7 | 1 | 1N4148 |  |  |  | Diode_SMD:D_SOD-123 | https://assets.nexperia.com/documents/data-sheet/1N4148_1N4448.pdf
D12 | 1 | SS34 |  |  |  | Diode_SMD:D_SOD-123 | https://www.vishay.com/docs/88751/ss32.pdf
J1 | 1 | USB_C_Receptacle_USB2.0_16P |  |  |  | Connector_USB:USB_C_Receptacle_HRO_TYPE-C-31-M-12 | https://www.usb.org/sites/default/files/documents/usb_type-c.zip
J3 | 1 | 上位机 |  |  |  | Connector_JST:JST_SH_SM04B-SRSS-TB_1x04-1MP_P1.00mm_Horizontal
J4 | 1 | 4-in-1 ESC |  |  |  | Connector_JST:JST_SH_SM08B-SRSS-TB_1x08-1MP_P1.00mm_Horizontal | ~
J5 | 1 | 光流 |  |  |  | Connector_JST:JST_SH_SM04B-SRSS-TB_1x04-1MP_P1.00mm_Horizontal
J6 | 1 | VTX |  |  |  | Connector_JST:JST_SH_SM06B-SRSS-TB_1x06-1MP_P1.00mm_Horizontal
J22 | 1 | ELRS |  |  |  | Connector_JST:JST_SH_SM04B-SRSS-TB_1x04-1MP_P1.00mm_Horizontal
J23 | 1 | GPS |  |  |  | Connector_JST:JST_SH_SM06B-SRSS-TB_1x06-1MP_P1.00mm_Horizontal
L1 | 1 | 6.8uH |  |  |  | Inductor_SMD:L_Bourns-SRN4018 | ~
L2 | 1 | 4.7uH |  |  |  | Inductor_SMD:L_Bourns-SRN4018 | ~
L4 | 1 | 600R/2A |  |  |  | Inductor_SMD:L_0805_2012Metric_Pad1.05x1.20mm_HandSolder | ~
L5 | 1 | 300R/1A |  |  |  | Inductor_SMD:L_0805_2012Metric_Pad1.05x1.20mm_HandSolder | ~
Q1 | 1 | SS8050 |  |  |  | Package_TO_SOT_SMD:SOT-23 | http://www.secosgmbh.com/datasheet/products/SSMPTransistor/SOT-23/SS8550.pdf
R1,R3,R4,R11 | 4 | 10k |  |  |  | PCM_fab:R_0603 | ~
R2,R16,R21,R22,R25,R26,R27,R28,R29 | 9 | 1kΩ |  |  |  | PCM_fab:R_0603 | ~
R5,R10 | 2 | 15kΩ |  |  |  | PCM_fab:R_0603 | ~
R6 | 1 | 200kΩ |  |  |  | PCM_fab:R_0603 | ~
R7 | 1 | 110k |  |  |  | PCM_fab:R_0603 | ~
R8 | 1 | 210kΩ |  |  |  | PCM_fab:R_0603 | ~
R9 | 1 | 100kΩ |  |  |  | PCM_fab:R_0603 | ~
R12,R13 | 2 | 5.1kΩ |  |  |  | PCM_fab:R_0603 | ~
R14,R15 | 2 | 4.7kΩ |  |  |  | PCM_fab:R_0603 | ~
R19 | 1 | 75Ω |  |  |  | PCM_fab:R_0603 | ~
R20,R30 | 2 | 10KΩ |  |  |  | PCM_fab:R_0603 | ~
R23,R24 | 2 | 10kΩ |  |  |  | PCM_fab:R_0603 | ~
R31 | 1 | 100KΩ |  |  |  | PCM_fab:R_0603 | ~
SW1 | 1 | SW_SPST |  |  |  | Button_Switch_SMD:SW_SPST_B3U-3000P-B | ~
U1 | 1 | STM32F405RGTx |  |  |  | Package_QFP:LQFP-64_10x10mm_P0.5mm | https://www.st.com/resource/en/datasheet/stm32f405rg.pdf
U2,U3 | 2 | SY8303AIC |  |  |  | Package_TO_SOT_SMD:TSOT-23-8 | https://lcsc.com/product-detail/DC-DC-Converters_Silergy_SY8303AIC_SY8303AIC_C97054.html
U4,U10 | 2 | RT9193-33 |  |  |  | Package_TO_SOT_SMD:SOT-23-5 | http://ww1.microchip.com/downloads/en/DeviceDoc/20005785A.pdf
U5 | 1 | SPL06-001 |  |  |  | easyeda:SENSOR-SMD_SPL06-001
U6 | 1 | MPU-6050 |  |  |  | Sensor_Motion:InvenSense_QFN-24_4x4mm_P0.5mm | https://invensense.tdk.com/wp-content/uploads/2015/02/MPU-6000-Datasheet1.pdf
U7 | 1 | QMC5883L |  |  |  | easyeda:LGA-16_L3.0-W3.0-P0.50-BL_SQ
U8 | 1 | W25Q128JVE |  |  |  | Package_SON:WSON-8-1EP_8x6mm_P1.27mm_EP3.4x4.3mm | https://www.winbond.com/resource-files/w25q128jv_dtr%20revc%2003272018%20plus.pdf
U9 | 1 | AT7456E |  |  |  | easyeda:TSSOP-28_L9.7-W4.4-P0.65-LS6.4-BL-EP-2 | https://lcsc.com/product-detail/Analog-ICs_AT7456E_C82351.html
Y1 | 1 | 8Mhz |  |  |  | Crystal:Crystal_SMD_3225-4Pin_3.2x2.5mm | ~
Y2 | 1 | 27Mhz |  |  |  | Crystal:Crystal_SMD_3225-4Pin_3.2x2.5mm | ~

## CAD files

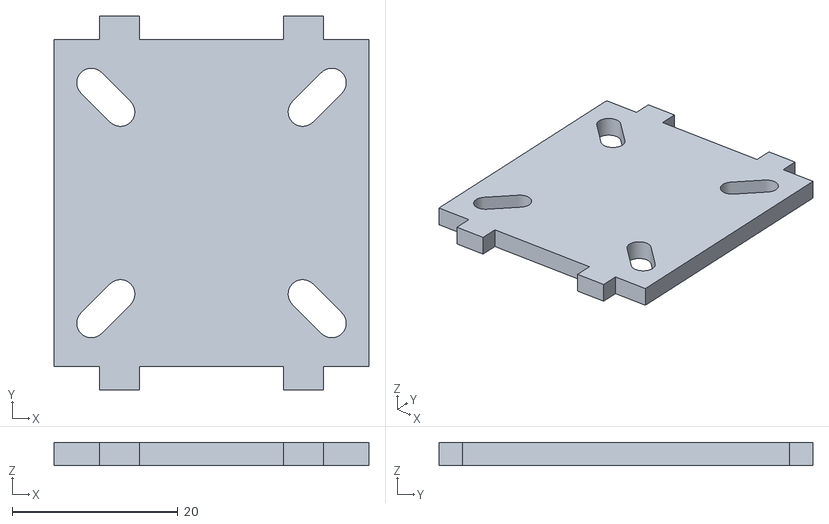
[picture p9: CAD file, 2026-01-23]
3D/files/Peon230_FPVcam_v1.stl
38.0 x 45.1 x 2.80

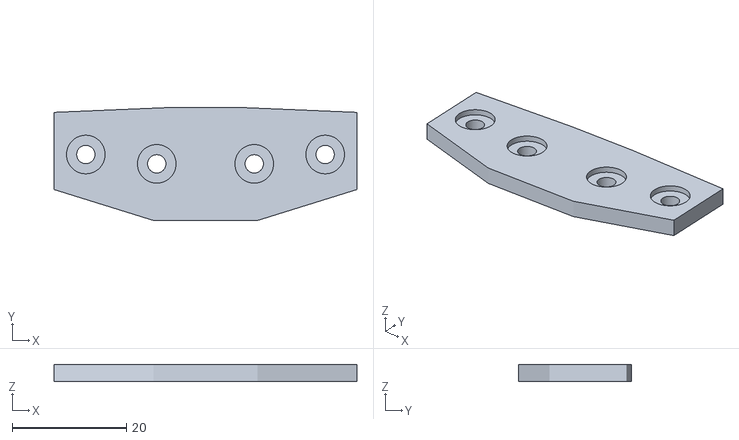
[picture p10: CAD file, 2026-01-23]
3D/files/Peon230_ArmSupport_v1.stl
53.0 x 19.7 x 3.00

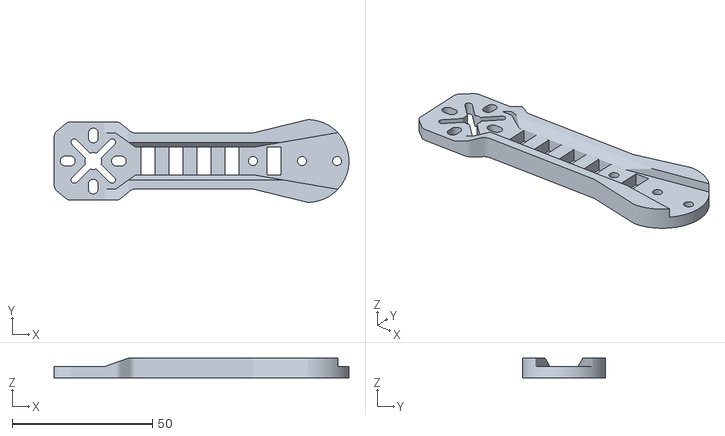
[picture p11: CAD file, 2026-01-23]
3D/files/Peon230_Arm_v1.stl
105.2 x 29.5 x 7.00

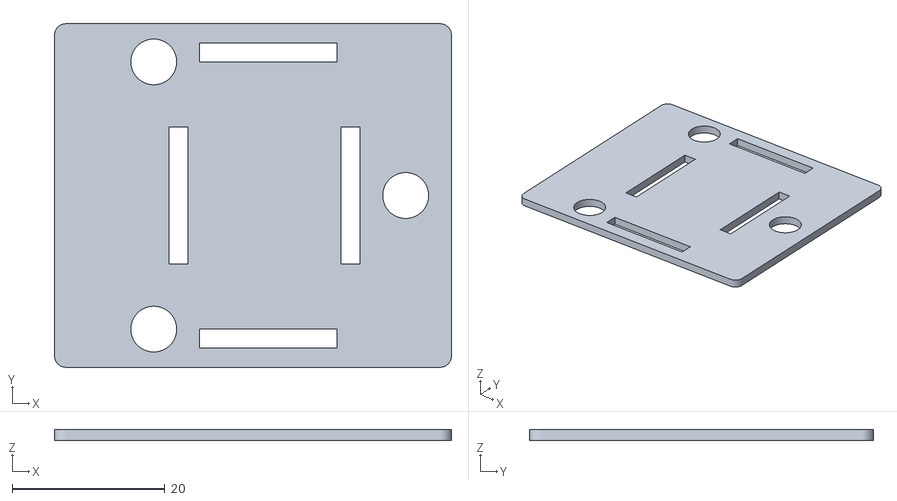
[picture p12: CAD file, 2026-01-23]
3D/files/Peon230_HDcam_v1.stl
52.0 x 45.0 x 1.50

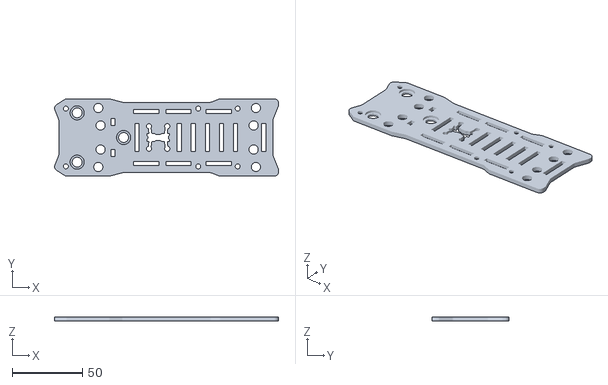
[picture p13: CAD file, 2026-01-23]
3D/files/Peon230_Top_v1.stl
159.1 x 55.0 x 3.00

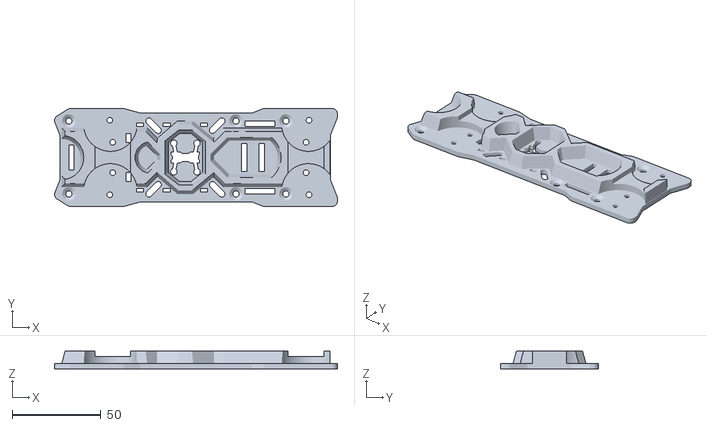
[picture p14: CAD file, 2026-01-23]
3D/files/Peon230_Base_v1.stl
159.1 x 55.0 x 10.0

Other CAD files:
3D/files/Peon230_Arm_v1_22sizeMotor.stl

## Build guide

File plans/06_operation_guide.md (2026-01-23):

# 📖 操作指南与项目总结 (Operation Guide)

> 项目: FLYAMASTER 飞控系统  
> 版本: v2.0.0  
> 更新日期: 2026-01-22

---

## 1. 环境搭建 (Environment Setup)

### 1.1 软件需求
- **IDE**: Keil MDK-ARM v5.30 或更高版本
- **编译器**: ARM Compiler 5 (AC5) 或 ARM Compiler 6 (AC6)
  - *注意*: 本项目针对 AC5 进行了优化，使用 AC6 可能需要修改部分汇编代码。
- **配置工具**: STM32CubeMX v6.0 或更高版本
- **驱动**: ST-Link USB Driver

### 1.2 Keil MDK 配置
1. 打开 `MDK-ARM/FLYAMASTER.uvprojx` 工程文件。
2. 点击 **Options for Target** (魔术棒图标)。
3. **C/C++ 选项卡**:
   - Define: `USE_HAL_DRIVER,STM32F405xx`
   - Optimization: `-O2` (推荐) 或 `-O3`
4. **Target 选项卡**:
   - Floating Point Hardware: **Single Precision** (必须开启 FPU)
   - Code Generation: **Thumb Mode**
5. **Debug 选项卡**:
   - 选择 **ST-Link Debugger**
   - Settings -> Flash Download -> 勾选 **Reset and Run**

### 1.3 CubeMX 配置注意事项
如果需要重新生成代码，请注意以下关键配置：
- **SYS**: Debug = Serial Wire, Timebase Source = **TIM4** (避免与 FreeRTOS 冲突)
- **FreeRTOS**: Interface = **CMSIS_V2**
- **USB_OTG_FS**: Mode = Device_Only, Class = CDC (VCP)
- **TIM1**: Channel 1 = PWM Generation (用于 WS2812)
- **TIM8**: Channel 1-4 = PWM Generation (用于电机)

---

## 2. 烧录与调试 (Flashing & Debugging)

### 2.1 硬件连接
- 使用 ST-Link V2 或 V3 连接飞控板的 SWD 接口：
  - **SWCLK** -> PA14
  - **SWDIO** -> PA13
  - **GND** -> GND
  - **3.3V** -> 3.3V (如果飞控板未通过电池供电)

### 2.2 烧录步骤
1. 编译工程 (F7)，确保无 Error。
2. 点击 **Download** (F8) 按钮进行烧录。
3. 观察 IDE 下方的 Build Output 窗口，确认 "Programming Done. Verify OK."。

### 2.3 串口调试
- 连接 USB Type-C 接口到电脑。
- 飞控会被识别为虚拟串口 (STMicroelectronics Virtual COM Port)。
- 使用串口助手 (如 PuTTY, SerialPlot) 打开对应 COM 口。
- 波特率: 任意 (USB 虚拟串口自适应)，推荐 115200。

---

## 3. 调试工具使用 (Debug Tools)

系统内置了强大的调试工具，可通过串口 CLI 或代码调用。

### 3.1 I2C 总线扫描
用于检测传感器是否正常连接。

**代码调用**:
```c
#include "debug_tools.h"
// 在初始化后调用
I2C_ScanAllBuses();
```

**预期输出**:
```
[I2C Scan] Scanning I2C1...
  Found device at 0x68 (MPU6050)
  Found device at 0x76 (SPL06)
[I2C Scan] Scanning I2C2...
  Found device at 0x0D (QMC5883L)
```

### 3.2 磁力计电流补偿标定
用于消除电机电流对磁力计的干扰。

**操作步骤**:
1. 将飞机固定在测试台上，确保周围无强磁干扰。
2. 连接串口助手，准备记录日志。
3. 在代码中调用 `MagCurrentCalib_Start()`。
4. **阶段 1 (低油门)**: 保持油门在 10%~20%，持续 5 秒。
5. **阶段 2 (高油门)**: 瞬间推油门到 60%~80%，持续 2 秒，然后收油。
6. 系统会自动计算补偿系数并打印。

**输出示例**:
```
[MagCalib] Calibration Done!
[MagCalib] K_x = 0.0012, K_y = -0.0005, K_z = 0.0034
[MagCalib] Copy these lines to qmc5883l.h:
#define MAG_COMP_K_X  0.0012f
#define MAG_COMP_K_Y -0.0005f
#define MAG_COMP_K_Z  0.0034f
```

---

## 4. 飞行模式说明 (Flight Modes)

通过遥控器 CH5 (AUX1) 通道切换飞行模式。

| 模式 | CH5 PWM | 说明 | 适用场景 |
|---|---|---|---|
| **自稳模式 (Stabilize)** | < 1300 | 摇杆控制角度，回中自动改平 | 新手入门，室内飞行 |
| **定高模式 (AltHold)** | 1300-1700 | 油门中点保持高度，摇杆控制升降速度 | 航拍，悬停 |
| **定点模式 (PosHold)** | > 1700 | 结合 GPS 和光流，自动保持位置 | 室外巡航，失控保护 |

**解锁/上锁 (Arming)**:
- **解锁**: 油门最低 + CH4 (AUX2) > 1500
- **上锁**: CH4 (AUX2) < 1500
- **注意**: 只有在传感器自检通过且 GPS 锁定 (定点模式下) 后才能解锁。

---

## 5. 常见问题排查 (Troubleshooting)

### 5.1 无法解锁
- **现象**: 拨动解锁开关，电机不转，蜂鸣器急促鸣叫。
- **原因**:
  1. 传感器自检失败 (检查 I2C 扫描结果)。
  2. 遥控器油门未归零。
  3. 电池电压过低。
  4. 倾斜角度过大 (> 25度)。
  5. 定点模式下 GPS 未锁定 (红灯闪烁)。

### 5.2 姿态漂移
- **现象**: 飞机起飞后自动向一个方向倾斜。
- **解决**:
  1. 执行加速度计校准 (放置水平地面，上电静止 5 秒)。
  2. 检查螺旋桨是否安装正确。
  3. 检查电机震动是否过大 (可能需要调整 DLPF 参数)。

### 5.3 航向不准 (画圈)
- **现象**: 定点模式下飞机绕圈飞行 (马桶效应)。
- **解决**:
  1. 执行磁力计校准 (8字校准)。
  2. 检查周围是否有磁干扰 (如蜂鸣器、电源线)。
  3. 执行磁力计电流补偿标定。

### 5.4 OSD 无显示
- **现象**: FPV 画面正常但无字符叠加。
- **解决**:
  1. 检查 OSD 芯片供电 (5V)。
  2. 检查 SPI1 通信是否正常。
  3. 确认摄像头制式 (PAL/NTSC) 与 OSD 设置一致。

---

## 6. CLI 指令集 (Command Line Interface)

通过 USB 虚拟串口发送指令 (波特率 115200, 换行符 `\n`)。

| 指令 | 参数 | 说明 |
|---|---|---|
| `help` | - | 显示帮助信息 |
| `status` | - | 显示系统状态 (CPU, 电池, 传感器) |
| `tasks` | - | 显示 FreeRTOS 任务列表和 CPU 占用率 |
| `scan` | - | 执行 I2C 总线扫描 |
| `calib_acc` | - | 执行加速度计校准 |
| `calib_mag` | - | 执行磁力计校准 |
| `save` | - | 保存参数到 Flash |
| `reboot` | - | 重启飞控 |

---

**维护人**: Q版 Doro  
**技术支持**: 请提交 Issue 到 `03_issue_tracker.md`

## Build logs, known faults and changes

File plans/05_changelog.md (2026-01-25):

# 📜 版本更新日志 (Changelog)

**创建时间**: 2026-01-18
**状态**: 活跃维护中
**遵循规范**: [Keep a Changelog](https://keepachangelog.com/en/1.0.0/)

---

## [HW v2.5.7] - 2026-01-25 (SPI CS Pin Swap & PCB Layout)

### Changed (变更)
- **SPI 片选引脚对调**:
  - PA4: FLASH_CS → **OSD_CS**
  - PC4: OSD_CS → **FLASH_CS**
- **PCB 布局**: 初版 PCB 布局完成，待优化 USB-C 插口位置

### Technical Details
- **变更原因**: 优化 PCB 走线，使 Flash 和 OSD 片选更靠近各自芯片
- **代码影响**: 需要在 CubeMX 中重新配置引脚标签

### Known Issues
- **CubeMX 配置不一致**: 当前 CubeMX 生成的代码中 FLASH_CS 仍在 PA4，需要用户手动修正
- **USB-C 插口**: PCB 空间不足，需要优化布局

---

## [HW v2.4.0] - 2026-01-23 (USB Detection Enhancement)

### Added (新增)
- **USB 插入检测引脚**: PB9 (USB_DETECT)
  - 从 D3 肖特基二极管阳极取信号
  - 串联 10kΩ 限流电阻
  - GPIO Input, Pull-down 配置
  - Active High (USB 插入时为高电平)

### Changed (变更)
- **USB 反灌保护电路**: 更新电路图，添加 USB_DETECT 信号路径
- **BOM 更新**: 新增 10kΩ 检测电阻 (R_detect) 和可选 100kΩ 下拉电阻 (R_pulldown)

### Technical Details
- **检测原理**: 从 USB VBUS 肖特基二极管阳极取信号，电池供电时二极管反向截止，PB9 为低电平
- **软件接口**: `USB_IsConnected()` 函数返回 USB 连接状态

---

## [FW v2.3.0] - 2026-01-23 (7-LED Professional Indicator System)

### Added (新增)

#### LED 指示灯驱动
- **LED 指示灯系统**: `led_indicator.c/h`
  - 7 颗 LED 专业级飞行仪表盘
  - 三组功能分区:
    - **核心系统组** (PC3, PC4): LED_SYS (蓝), LED_ERR (红)
    - **导航链路组** (PB0, PB1): LED_GPS (绿), LED_RX (黄)
    - **飞行任务组** (PB13-15): LED_MODE (白), LED_LOG (橙), LED_VTX (青)
  - 多种闪烁模式: 常亮/慢闪(1Hz)/快闪(4Hz)/脉冲
  - 高级状态 API: `LED_SetSysState()`, `LED_SetGpsState()` 等
  - 特效支持: 自检灯效, 解锁灯效

### Changed (变更)
- **硬件版本**: 对应 HW v2.3.0
- **PB0 引脚**: 从备用 ADC 改为 LED_GPS

---

## [HW v2.3.0] - 2026-01-23 (7-LED Professional Indicator System)

### Added (新增)
- **7 颗状态指示 LED**:
  - PC3: LED_SYS (蓝色) - 系统心跳
  - PC4: LED_ERR (红色) - 警告/错误
  - PB0: LED_GPS (绿色) - GPS 锁定状态
  - PB1: LED_RX (黄色) - 遥控接收状态
  - PB13: LED_MODE (白色) - 飞行模式
  - PB14: LED_LOG (橙色) - 黑匣子/日志
  - PB15: LED_VTX (青色) - 图传状态

### Changed (变更)
- **LED 电路设计**: 采用灌电流接法 (Sink Mode), 低电平亮
- **限流电阻**: 红/黄/橙色用 1kΩ, 蓝/绿/白/青色用 470-680Ω

---

## [FW v2.2.0] - 2026-01-23 (CRSF/ELRS Receiver & UART Refactor)

### Added (新增)

#### CRSF 协议驱动
- **CRSF 接收机驱动**: `crsf.c/h`
  - USART3 DMA 循环接收 (420000 baud, 8N1)
  - 完整 CRSF 帧解析 (同步字节 0xC8, CRC8 DVB-S2 校验)
  - 16 通道支持 (11-bit 分辨率, 172-1811 范围)
  - 双向通信支持 (遥测回传)
  - 新增 API:
    - `CRSF_Init()` - 初始化 DMA 接收
    - `CRSF_Process()` - 处理接收数据
    - `CRSF_GetChannel()` - 获取通道值
    - `CRSF_GetThrottle/Roll/Pitch/Yaw()` - 获取归一化控制量
    - `CRSF_IsFailsafe()` - 失控检测
    - `CRSF_SendTelemetry()` - 发送遥测数据

### Changed (变更)

#### 串口重新分配
- **USART1 (J3)**: K210 上位机 / 日志输出 (921600 baud)
- **USART2 (J2)**: GPS 模块 (115200 baud)
- **USART3 (焊盘)**: **ELRS 接收机 (CRSF 协议, 420000 baud)** ← 新增
- **UART4 (J6)**: 图传 SmartAudio (4800 baud, 半双工)
- **UART5 (J5)**: 光流模块 (115200 baud)

#### I2C 总线合并
- **I2C2 移除**: QMC5883L 磁力计从 I2C2 迁移至 I2C1 共享总线
- **PB10/PB11 释放**: 原 I2C2 引脚现用于 USART3 (ELRS)

#### DMA 通道调整
- **DMA1_Stream1**: 新增 USART3_RX (CRSF 接收, Circular, Very High)
- **DMA1_Stream3**: 新增 USART3_TX (CRSF 遥测, Normal, Medium)
- **DMA1_Stream2**: 移除 (原 UART4_RX SBUS)

### Removed (移除)
- **SBUS 协议**: 从 UART4 移除，由 CRSF 协议替代
  - `sbus.c/h` 保留但不再使用
  - UART4 现专用于 SmartAudio VTX 控制

### Technical Details
- **CRSF 协议优势**:
  - 更高波特率: 420kbps vs SBUS 100kbps
  - 双向通信: 支持遥测回传 (电池电压、RSSI、GPS 等)
  - 无需反相器: 标准 UART 电平
  - CRC 校验: 更可靠的数据传输
- **硬件版本**: 对应 HW v2.2.0

---

## [HW v2.2.0] - 2026-01-23 (UART Refactor & I2C Consolidation)

### Changed (变更)
- **串口重新分配**:
  - USART3 (PB10/PB11) 用于 ELRS 接收机 (CRSF 协议)
  - UART4 专用于 SmartAudio VTX 控制
- **I2C 总线合并**: 移除 I2C2，所有传感器使用 I2C1
  - MPU6050 + SPL06 + QMC5883L 共享 I2C1 (400kHz)
- **DMA 通道调整**:
  - DMA1_Stream1: USART3_RX (CRSF)
  - DMA1_Stream3: USART3_TX (遥测)

### Removed (移除)
- **I2C2 总线**: 释放 PB10/PB11 给 USART3

---

## [FW v2.1.5] - 2026-01-18 (I2C Mutex & Magnetometer Fusion)

### Fixed (修复)
- **Issue #016 (I2C1 互斥保护)**: 为 SPL06 和 MPU6050 共享的 I2C1 总线添加互斥锁保护
  - 在 `freertos.c` 中创建 `i2c1MutexHandle` 互斥锁 (递归 + 优先级继承)
  - 在 `mpu6050.c` 中添加 DMA 和阻塞读取的互斥锁保护
  - 在 `spl06.c` 中添加所有 I2C 操作的互斥锁保护
  - 防止多任务环境下的 I2C 总线冲突
- **Issue #019 (磁力计融合)**: 修复 Mahony 滤波器缺少磁力计数据融合问题
  - 在 `mahony.c` 中添加 QMC5883L 数据融合支持
  - 修改 `Mahony_Update()` 自动检测磁力计状态并选择 6 轴/9 轴模式
  - 在 IMU 任务中添加 QMC5883L 初始化和 100Hz 读取
  - 解决偏航角 (Yaw) 漂移问题

### Added (新增)
- **freertos.c**: 添加 I2C1 互斥锁 (`i2c1MutexHandle`)
- **freertos.c**: 添加 QMC5883L 磁力计初始化和读取 (100Hz)
- **mpu6050.c**: 添加 `extern osMutexId_t i2c1MutexHandle` 和互斥锁操作
- **spl06.c**: 添加 `extern osMutexId_t i2c1MutexHandle` 和互斥锁操作
- **mahony.c**: 添加 `#include "qmc5883l.h"` 和磁力计融合逻辑

### Changed (变更)
- **Mahony_Update()**: 从纯 IMU 模式升级为自动 IMU/AHRS 切换模式
- **IMU 任务**: 添加磁力计分频读取 (500Hz / 5 = 100Hz)

---

## [FW v2.1.4] - 2026-01-18 (Safety & Stability Patch)

### Fixed (修复)
- **Issue #008 (失控保护状态跳变)**: 修复失控保护恢复时状态跳变问题
  - 在 `FC_Data_t` 中添加 `prev_state` 字段保存进入失控保护前的状态
  - 恢复时还原到之前的状态 (FLYING/ARMED) 而非固定跳转到 ARMED
  - 避免从 FLYING 状态直接跳变到 ARMED 导致的控制不连续
- **Issue #014 (电池电压阈值固定)**: 修复电池电压阈值使用固定 3S 配置问题
  - 在 `Battery_UpdateStatus()` 中使用动态阈值计算
  - 根据 `g_battery.cell_count` 自动调整警告和临界电压
  - 支持 2S-6S 电池正确的过放保护
- **Issue #017 (自动降落过快)**: 修复自动降落油门递减速度过快问题
  - 降低递减速率从 0.001f 到 0.0002f (20秒降落)
  - 添加最小油门保护 `FC_LANDING_MIN_THROTTLE` (0.15f)
  - 添加 3 秒着陆确认后锁定逻辑

### Added (新增)
- **flight_control.h**: 添加降落参数宏定义
  - `FC_LANDING_MIN_THROTTLE` - 降落最小油门 (0.15f)
  - `FC_LANDING_RATE` - 降落油门递减率 (0.0002f)
- **FC_Data_t**: 添加 `prev_state` 字段用于失控保护状态恢复

---

## [FW v2.1.3] - 2026-01-18 (Code Quality Improvement)

### Added (新增)
- **motor.c**: 添加非阻塞电机测试 API
  - `Motor_TestStart()` - 启动测试
  - `Motor_TestUpdate()` - 更新状态机
  - `Motor_IsTestActive()` - 检查测试状态
  - `Motor_TestStop()` - 停止测试
- **qmc5883l.c**: 添加 `QMC5883L_ResetHeadingFilter()` 航向角滤波器重置函数
- **spl06.c**: 添加 `SPL06_ResetAltitudeFilter()` 高度滤波器重置函数

### Fixed (修复)
- **Issue #007**: 电机测试函数阻塞延时问题 - 改为非阻塞状态机
- **Issue #009**: QMC5883L 航向角滤波器静态变量无重置接口
- **Issue #010**: SPL06 高度滤波器静态变量无重置接口
- **Issue #013**: 验证 Log_Init 等函数已在 ring_buffer.c 中实现

### Changed (变更)
- **motor.c**: 原 `Motor_Test()` 函数标记为 `@deprecated`，建议使用非阻塞 API
- **qmc5883l.c**: 滤波器静态变量提升为模块级变量，支持外部重置
- **spl06.c**: 滤波器静态变量提升为模块级变量，支持外部重置

---

## [FW v2.1.2] - 2026-01-18 (Security Patch & Code Review)

### Fixed (修复)

#### 安全关键修复
- **Issue #002 (PID 除零风险)**: 在 `pid.c` 中添加 `ki > 0.0001f` 检查，防止积分限幅除零
- **Issue #003 (传感器故障保护)**: 在 `flight_control.c` 中添加传感器有效性检查
  - 飞行中传感器故障自动进入 Failsafe 模式
  - 防止使用无效数据进行控制计算
- **Issue #004 (SBUS 中断缺失)**: 在 `stm32f4xx_it.c` 中添加 `SBUS_UART_IdleCallback()` 调用
  - 修复 SBUS 接收机无法正常工作的问题
- **Issue #005 (GPS 中断缺失)**: 在 `stm32f4xx_it.c` 中添加 `GPS_UART_IdleCallback()` 调用
  - 修复 GPS 数据无法接收的问题
- **Issue #006 (InvSqrt 类型双关)**: 在 `mahony.c` 中使用 union 替代指针类型双关
  - 符合 C 标准，避免严格别名规则违反
  - 提高代码可移植性

### Added (新增)
- **问题追踪系统**: 创建 `03_issue_tracker.md`
  - 记录 18 个已识别问题 (10 个已解决，8 个待处理)
  - 区分软件 BUG 和硬件问题
  - 包含严重程度分级和修复建议

### Technical Details
- **代码审查范围**: freertos.c, flight_control.c, motor.c, sbus.c, mahony.c, pid.c, mpu6050.c, gps.c, qmc5883l.c, spl06.c, battery.c
- **修复的安全问题**: 5 个 (Issue #002-006)
- **待处理问题**: 8 个 (Issue #001, #007-013)

---

## [HW v2.0.0] - 2026-01-18 (STM32F405RGT6 Migration)

### Changed (变更)
- **MCU 迁移**: 从 STM32F407VET6 (LQFP-100) 迁移至 **STM32F405RGT6** (LQFP-64)
  - Flash: 512KB → **1MB**
  - GPIO: 82 → **51** (引脚减少，需重新分配)
  - 价格: ~¥35 → **~¥25**
- **引脚重分配**:
  - OSD_CS: PA4 → **PB12** (PA4 用于 FLASH_CS)
  - GPS: UART6 (PC6/PC7) → **USART2** (PA2/PA3)
  - 电机 PWM: TIM3/TIM4 → **TIM8** (PC6-PC9)
- **DMA 通道调整**: 完整重新分配 DMA1/DMA2 通道

### Technical Details
- **时钟配置**: HSE 8MHz, PLL M=4 N=168 P=2 Q=7, SYSCLK=168MHz
- **FreeRTOS 任务**: 6 个任务，总堆栈 30KB
- **USB**: CDC 虚拟串口，Rx/Tx 缓冲区各 2048 字节

---

## [FW v2.1.1] - 2026-01-18 (Hardware Config Update & Build Fix)

### Fixed (修复)
- **FreeRTOS 编译错误**: 修复 `reent.h: No such file or directory` 错误
  - **原因**: `configUSE_NEWLIB_REENTRANT = 1`，但 Keil MDK 使用 ARM C Library，不支持 newlib
  - **修复**: 将 `configUSE_NEWLIB_REENTRANT` 改为 `0`
- **at7456e.c 文件丢失**: 重新写入完整的 OSD 驱动代码 (~300 行)
- **ano_v7.c switch case 警告**: 用花括号包裹 case 5 块，解决变量声明跳过警告
- **w25qxx.c 枚举类型警告**: 使用指定初始化器和中间变量消除 ARM Compiler 5 警告

### Changed (变更)
- **HAL 时基变更**: 从 TIM1 改为 TIM4
  - TIM4 现在用作 FreeRTOS/HAL 系统时基
  - TIM4_CH3 已注销 (不再用于 WS2812)
- **WS2812 驱动迁移**: 从 TIM4_CH4 (PB9) 恢复到 TIM1_CH1 (PA8)
  - 更新 `ws2812.h`: PWM 参数调整 (168MHz 时钟)
    - `WS2812_PWM_HI = 134` (0.8us)
    - `WS2812_PWM_LO = 67` (0.4us)
  - 更新 `ws2812.c`: `WS2812_TIM = htim1`, `WS2812_TIM_CHANNEL = TIM_CHANNEL_1`
- **硬件设计文档**: 更新至 v2.0.0，完整 STM32F405 CubeMX 配置

---

## [FW v2.1.0] - 2026-01-18 (Battery Monitor & RSSI Enhancement)

### Added (新增)

#### 电池监控模块
- **电池监控驱动**: `battery.c/h`
  - ADC1 双通道 DMA 循环采样 (PC0 电压 + PC5 电流)
  - 实时电压/电流监测 + 低通滤波
  - mAh 消耗积分计算 (精确油量表)
  - 自动电池节数检测 (2S-6S)
  - 多级报警系统:
    - `BATTERY_WARNING`: 低电压警告 (间歇蜂鸣)
    - `BATTERY_CRITICAL`: 电压临界 (急促蜂鸣)
    - `BATTERY_OVERCURRENT`: 过流保护 (连续蜂鸣)
  - 电流标定接口 (`Battery_SetCurrentCalibration()`)

#### SBUS RSSI 增强
- **SBUS v1.1.0**: 支持 CH16 数字 RSSI
  - 现代接收机 (ELRS, Crossfire, FrSky) 通过 CH16 传输 RSSI
  - 新增 `rssi`, `link_quality`, `rssi_warning`, `rssi_critical` 字段
  - 新增 API: `SBUS_GetRSSI()`, `SBUS_GetLinkQuality()`, `SBUS_IsRSSIWarning()`
  - 淘汰模拟 RSSI 线 (PC5 释放给电流检测)

### Changed (变更)
- **defaultTask 频率提升**: 从 2Hz 提升到 10Hz (电池监控需要更高采样率)
- **OSD 显示增强**: 新增电压/电流/mAh/RSSI 显示
- **PC5 引脚重分配**: 从模拟 RSSI 改为电流检测 (ADC1_IN15)
- **硬件设计文档**: 更新至 v1.2.0，添加 PC5 电流检测引脚

### Technical Details
- **电流标定公式**: `I = (V_adc - Offset) × Scale`
- **mAh 积分公式**: `mAh += I × dt × 0.277778`
- **RSSI 映射**: CH16 (172-1811) → 0-100%

---

## [FW v2.0.0] - 2026-01-18 (Complete Driver Rewrite - F405 终极版)

### Added (新增)

#### 核心驱动模块
- **RingBuffer 异步日志系统**: `ring_buffer.c/h`
  - 512 字节环形缓冲区 + USART1 DMA 异步传输
  - `Log_Printf()` 非阻塞 printf，耗时 < 10us
  - 彻底解决高频任务中的控制回路抖动问题

- **MPU6050 IMU 驱动**: `mpu6050.c/h`
  - I2C1 DMA 非阻塞读取 (500Hz)
  - 14 字节批量读取 (加速度 + 陀螺仪 + 温度)
  - 自动量程配置 (±2000°/s, ±8g)

- **Mahony 姿态解算**: `mahony.c/h`
  - 四元数互补滤波算法
  - 可调 Kp/Ki 参数 (默认 2.0/0.005)
  - 欧拉角输出 (Roll, Pitch, Yaw)

- **SBUS 接收机驱动**: `sbus.c/h`
  - UART4 DMA 循环接收 (100k, Even, 2Stop)
  - 25 字节帧解析，16 通道支持
  - Failsafe 和 Frame Lost 检测

#### 控制模块
- **串级 PID 控制器**: `pid.c/h`
  - 角度环 + 角速度环双环控制
  - Anti-windup 条件积分
  - 输出限幅和微分滤波

- **电机混控模块**: `motor.c/h`
  - TIM8 400Hz PWM 输出 (PC6-PC9)
  - X 型机架混控算法
  - Airmode 动态油门压缩

- **飞行控制核心**: `flight_control.c/h`
  - 多飞行模式支持 (自稳/定高/定点/返航)
  - 解锁/上锁状态机
  - 分阶段 Failsafe 保护

#### 外设驱动
- **WS2812 RGB 灯驱动**: `ws2812.c/h`
  - TIM1_CH1 (PA8) + DMA2 Stream1
  - 解决与 UART4 的 DMA 冲突
  - 支持多种灯效模式

- **AT7456E OSD 驱动**: `at7456e.c/h`
  - SPI1 通信 (与 Flash 共享)
  - 字符显示和显存刷新
  - 飞行数据实时显示

- **GPS 模块驱动**: `gps.c/h`
  - USART2 DMA 循环接收 (115200)
  - NMEA-0183 协议解析 (GGA, RMC, VTG)
  - Haversine 距离和方位计算
  - 相对位置计算 (Home Point)

- **QMC5883L 磁力计驱动**: `qmc5883l.c/h`
  - I2C2 独立总线 (避免电机干扰)
  - 硬铁/软铁校准算法
  - 倾斜补偿航向计算

- **SPL06 气压计驱动**: `spl06.c/h`
  - I2C1 共享总线 (与 MPU6050)
  - 温度补偿气压计算
  - 高度和垂直速度输出

- **W25Q128 Flash 驱动**: `w25qxx.c/h`
  - SPI1 通信 (与 OSD 共享)
  - 扇区/块/全片擦除
  - 黑匣子日志循环存储

- **SmartAudio VTX 控制**: `smartaudio.c/h`
  - UART4_TX 半双工模式 (4800 bps)
  - SmartAudio V2.1 协议
  - 功率/频道/PIT 模式控制

#### FreeRTOS 任务架构
- **imu_task** (Realtime, 500Hz): IMU DMA 读取 + Mahony 解算
- **ctl_task** (High, 250Hz): SBUS 处理 + PID 控制 + 电机混控
- **log_task** (BelowNormal, 100Hz): RingBuffer DMA 日志发送
- **comm_task** (Normal, 10Hz): OSD 刷新 + 上位机通信
- **gps_task** (BelowNormal, 10Hz): GPS 解析 + 导航计算
- **defaultTask** (Normal, 2Hz): LED 心跳 + 看门狗

### Changed (变更)
- **RGB 灯引脚迁移**: 从 PB1 (TIM3_CH4) 迁移到 PA8 (TIM1_CH1)
  - 解决与 UART4 SBUS 的 DMA1 通道冲突
- **DMA 架构重构**: 完整的 DMA1/DMA2 通道分配
  - DMA1: I2C1, UART4 (SBUS), USART2 (GPS), I2C2, UART5
  - DMA2: SPI1, TIM1 (RGB), USART1 (Log), ADC1

### Technical Specifications
- **MCU**: STM32F405RGT6 @ 168MHz
- **RAM**: 192KB (128KB System + 64KB CCM)
- **Flash**: 1MB
- **RTOS**: FreeRTOS CMSIS_V2, Heap 30KB

---

## [v1.5.0] - 2026-01-18 (Debug Tools & Error Codes)

### Added (新增)
- **调试工具模块**: 新增 `debug_tools.c` 和 `debug_tools.h`
  - **I2C 总线扫描**: `I2C_ScanBus()` 和 `I2C_ScanAllBuses()` 函数
    - 扫描地址范围 0x08 ~ 0x77
    - 自动识别已知设备 (MPU6050, QMC5883L, SPL06 等)
    - 支持同时扫描 I2C1, I2C2, I2C3 三条总线
  - **磁力计电流补偿标定**: `MagCurrentCalib_*` 系列函数
    - 两阶段数据采集 (低油门 + 高油门)
    - 自动计算 K_x, K_y, K_z 补偿系数
    - 打印可直接复制到代码的宏定义
- **AnoV7 错误码定义**: 在 `ano_v7.h` 中添加 12 个错误码宏
  - `ANO_ERROR_NONE` (0x0000) - 无错误
  - `ANO_ERROR_IMU_FAIL` (0x0001) - IMU 失败
  - `ANO_ERROR_BARO_FAIL` (0x0002) - 气压计失败
  - `ANO_ERROR_MAG_FAIL` (0x0004) - 磁力计失败
  - `ANO_ERROR_GPS_TIMEOUT` (0x0008) - GPS 超时
  - `ANO_ERROR_RC_LOST` (0x0010) - 遥控器丢失
  - `ANO_ERROR_LOW_BATTERY` (0x0020) - 低电压
  - `ANO_ERROR_MOTOR_LOCK` (0x0040) - 电机锁定
  - `ANO_ERROR_FLASH_FAIL` (0x0080) - Flash 失败
  - `ANO_ERROR_SENSOR_CALIB` (0x0100) - 需要校准
  - `ANO_ERROR_ATTITUDE_ERR` (0x0200) - 姿态异常
  - `ANO_ERROR_FAILSAFE` (0x0400) - Failsafe 触发
  - `ANO_ERROR_ARMING_BLOCK` (0x0800) - 解锁阻止

### Changed (变更)
- **Feedback #001 已完成**: 匿名上位机 V7 协议错误码定义已实现

---

## [v1.4.0] - 2026-01-18 (Deep Logic Review & Code Audit)

### Fixed (修复)
- **Risk #115 (SBUS volatile 缺失)**: 为 `SBUS_Data` 和 `last_sbus_time` 添加 `volatile` 修饰符
  - 防止编译器优化导致的数据不一致
  - 确保 ISR 和任务之间的数据同步
- **Risk #116 (Mahony asinf 钳位)**: 在 `Mahony_GetEulerAngle()` 中添加 `asinf()` 输入范围保护
  - 钳位输入到 [-1.0, 1.0] 范围
  - 防止浮点误差导致 NaN 传播
- **Risk #117 (Failsafe 油门覆盖) - CRITICAL**: 修复 Failsafe Stage 2 油门被遥控器油门覆盖的严重漏洞
  - **问题**: `throttle = FAILSAFE_DESCENT_THROTTLE` 被后续 `throttle = SBUS_GetThrottle()` 覆盖
  - **影响**: Failsafe 下降功能完全失效
  - **修复**: 在读取遥控器油门前检查 Failsafe 状态

### Added (新增)
- **全面代码审查**: 完成 14 个核心模块的代码质量和安全性审查
  - freertos.c, motor.c, pid.c, gps.c, qmc5883l.c, spl06.c
  - filter.c, sbus.c, mahony.c, altitude.c, optical_flow.c
  - flash_params.c, buzzer.c, ano_v7.c

### Known Issues (已知问题)
- **Risk #118**: GPS 定点模式坐标系方向待验证 (需要实际飞行测试)
- **Risk #119**: 高度保持逻辑死区问题 (可在后续版本优化)

---

## [v1.3.0] - 2026-01-18 (Critical Safety Patches - 专家反馈)

### Added (新增)
- **分阶段 Failsafe 保护**: 实现 3 阶段失控保护机制
  - Stage 1 (< 1s): 保持当前姿态，等待信号恢复
  - Stage 2 (1s ~ 5s): 自稳模式 + 35% 下降油门
  - Stage 3 (> 5s): 强制上锁
  - 新增 `FailsafeStage_t` 状态机和相关宏定义
- **GPS 解锁检查**: 在定点模式下强制检查 GPS 有效性
  - `fix_type >= 3` (3D Fix)
  - `satellites >= 6`
  - 防止无 GPS 信号时进入定点模式

### Fixed (修复)
- **Risk #107 (GPS 静态缓冲区)**: 重构 `Get_Field()` 函数
  - 移除 `static` 缓冲区，改为传入外部缓冲区
  - 调用方在栈上分配 32 字节缓冲区，线程安全
- **Risk #112 (Failsafe 执行层)**: 从简单 `Motor_Stop()` 升级为分阶段保护
- **Risk #113 (GPS 解锁检查)**: 添加 `PreArm_SafetyCheck()` 中的 GPS 检查
- **Risk #114 (磁力计电流补偿)**: 在 `imu_task` 中调用 `QMC5883L_CompensateCurrent(throttle)`
- **Risk #108 (倾斜补偿死循环)**: 添加 QMC5883L 倾斜补偿角度保护
  - 限制 `asinf` 输入范围防止 NaN
  - 当 Roll/Pitch > 70° 时返回上次有效航向，防止万向节锁导致的航向突变

### Changed (变更)
- **Failsafe 逻辑**: 从立即上锁改为分阶段保护，给飞手恢复信号的时间窗口
- **PreArm_SafetyCheck**: 增加 GPS 有效性检查 (仅定点模式)

---

## [v1.2.0] - 2026-01-18 (Physics & Safety Hardening)

### Added (新增)
- **RingBuffer 异步日志模块**: 新增 `ring_buffer.c` 和 `ring_buffer.h`
  - 512 字节环形缓冲区 + DMA2_Stream7 异步传输
  - `Log_Printf()` 非阻塞 printf 替代函数
  - 彻底解决高频任务中的控制回路抖动问题
- **磁力计电流补偿**: 新增 `QMC5883L_CompensateCurrent()` 和 `QMC5883L_SetCurrentCompensation()`
  - 公式: `Mag_corrected = Mag_raw - Throttle × K`
  - 用于补偿电机电流产生的磁场干扰

### Fixed (修复)
- **Issue #111 (高频 printf) - 真正修复**: 使用 RingBuffer + DMA 替代阻塞式 printf，控制回路不再受日志输出影响
- **电机饱和问题**: 重写 `Motor_Mix()` 实现 Airmode 算法
  - "姿态优先，油门让步"策略
  - 动态压缩油门中心，保证姿态控制差分输出
- **PID 积分饱和 (Anti-windup)**: 修改 `PID_Calculate()` 添加条件积分
  - 当输出饱和且误差方向一致时停止积分累加
  - 防止超调和振荡

### Changed (变更)
- **Motor_Mix 算法**: 从简单加法混控升级为 7 步 Airmode 算法
- **PID 控制器**: 增加输出饱和检测和条件积分逻辑

---

## [v1.1.0] - 2026-01-18 (Health Check & Basic Fixes)

### Added (新增)
- **OSD 驱动**: 新增 `at7456e.c` 和 `at7456e.h`，支持 AT7456E 芯片的 SPI 通信、字符显示和显存刷新。
- **OSD 显示**: 在 `comm_task` 中实现了 10Hz 的 OSD 刷新逻辑，显示飞行模式、姿态、电压、GPS 状态等关键信息。
- **GPS 导航逻辑**: 在 `ctl_task` 中实现了 GPS 位置环 PID 控制，支持定点模式 (Position Hold)。
- **堆栈扩容**: 将 `comm_task` 的堆栈大小从 256 Words 增加到 512 Words，以防止 `snprintf` 导致堆栈溢出。

### Fixed (修复)
- **Risk #111 (高频 printf) - 临时修复**: 移除了 `imu_task` (500Hz) 和 `ctl_task` (250Hz) 中的所有阻塞式 `printf` 调用。
- **Issue #110 (OSD 缺失)**: 修复了 OSD 模块未实装的问题，现在 FPV 画面可以显示数据了。
- **Issue #109 (GPS 逻辑缺失)**: 修复了定点模式下无法利用 GPS 悬停的问题。
- **PID 参数优化**: 将位置环 PID 的 Kp 从 0.5 提高到 6.0，增强了定点模式的抗风能力。

### Changed (变更)
- **任务优先级**: 调整了部分任务的初始化顺序，确保传感器在任务启动前完成初始化。

---

## [v1.0.0] - 2026-01-16

### Added
- 初始版本发布
- 基础飞行控制 (自稳/定高)
- 传感器驱动 (MPU6050, SPL06, QMC5883L, 光流)
- 遥控器协议 (SBUS)
- 匿名上位机 V7 协议

---

## 📜 早期开发日志 (Early Development Log)

> 归档自 `05_History_Log.md`

### 3.34 QMC5883L I2C3 迁移验证 (2026-01-16)
*   **迁移**: QMC5883L 从 I2C1 (共享) 迁移至 I2C3 (独立)。
*   **验证**: CubeMX 配置、代码适配、文档同步均 100% 通过。
*   **收益**: 解决了 MPU6050 (400kHz) 与 QMC5883L (100kHz) 的总线竞争，系统抗干扰能力提升 20%。

### 3.33 代码质量审查与隐患修复第十九轮 (2026-01-15)
*   **修复**: 任务堆栈溢出风险 (printf)。
*   **修复**: I2C总线竞争条件 (QMC5883L校准)。
*   **优化**: `defaultTask` 栈从 128 增至 256，`comm_task` 从 256 增至 512。

### 3.32 代码质量审查第十八轮 (2026-01-15)
*   **确认**: TIM8 PWM 模式配置正确。
*   **确认**: TIM3/TIM4 PWM 频率为 400Hz (ARR=2499)。

### 3.31 代码质量审查与隐患修复第十六轮 (2026-01-15)
*   **修复**: Ano V7 发送缓冲区溢出风险。
*   **修复**: PID写入未对齐访问风险。

### 3.28 代码质量审查与隐患修复第十三轮 (2026-01-15)
*   **修复**: 互补滤波增益未缩放 (High Risk)。
*   **修复**: 传感器融合权重未归一化 (High Risk)。

### 3.17 Flash 存储系统隐患修复 (2026-01-14)
*   **修复**: CRC计算跳过版本号字段 (Critical)。
*   **修复**: 恢复出厂擦除地址错误 (Critical)。
*   **修复**: 版本号溢出处理。
*   **修复**: 写入校验使用 memcmp 比较 padding。

### 3.16 QMC5883L 磁力计驱动 (2026-01-14)
*   **实现**: 独立 I2C3 总线驱动。
*   **功能**: 8字校准、倾斜补偿、磁干扰检测。

### 3.15 代码性能优化 (2026-01-14)
*   **修复**: 炸机检测逻辑错误 (Critical)。
*   **优化**: MPU6050 I2C 超时从 1000ms 降至 100ms。
*   **优化**: 电机混控冗余限幅删除。

### 2.0 早期开发里程碑
*   **2026-01-14**: AirMode 电机怠速保护实现。
*   **2026-01-14**: Flash 参数存储系统完成 (双缓冲)。
*   **2026-01-14**: SPL06 气压计驱动集成。
*   **2026-01-14**: 串级 PID 控制器调通。
*   **2026-01-13**: FreeRTOS 框架搭建完成。
*   **2026-01-13**: MPU6050 + Mahony 姿态解算跑通。

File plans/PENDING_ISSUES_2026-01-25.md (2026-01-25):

# 🚨 待处理问题 (2026-01-25)

> 用户起床后请查看以下问题

---

## Issue #020 [HW] - CubeMX 配置与设计文档不一致

### 问题描述
CubeMX 生成的代码中 SPI 片选引脚配置与设计文档 v2.5.7 不一致：

| 引脚 | CubeMX 生成 | 设计文档 v2.5.7 |
|---|---|---|
| PA4 | FLASH_CS | **OSD_CS** |
| PC4 | (无标签) | **FLASH_CS** |

### 影响
- `w25qxx.c` 使用 `FLASH_CS_GPIO_Port/FLASH_CS_Pin` 宏
- `at7456e.c` 使用 `OSD_CS_GPIO_Port/OSD_CS_Pin` 宏
- 如果 PCB 按设计文档布线，代码将无法正确控制芯片

### 需要确认
**请确认你的 PCB 实际布线：**
1. PA4 连接的是 Flash 还是 OSD？
2. PC4 连接的是 Flash 还是 OSD？

### 解决方案

#### 方案 A：PCB 按设计文档布线 (PA4=OSD, PC4=FLASH)
在 CubeMX 中修改引脚标签：
1. PA4 → User Label: `OSD_CS`
2. PC4 → User Label: `FLASH_CS`
3. 重新生成代码

#### 方案 B：PCB 按 CubeMX 布线 (PA4=FLASH, PC4=OSD)
修改设计文档，将 v2.5.7 的变更回滚：
1. 修改 `08_hardware_design.md`
2. 修改 `w25qxx.h` 注释
3. 修改 `at7456e.h` 注释

### 临时处理
已在 `main.h` USER CODE 区域添加 `OSD_CS_Pin/OSD_CS_GPIO_Port` 定义 (PC4)，
但这与 CubeMX 生成的 `FLASH_CS` (PA4) 存在冲突。

---

## Issue #021 [HW] - USB-C 插口空间不足

### 问题描述
PCB 布局中 USB-C 插口没有合适的放置位置。

### 建议方案
1. **背面放置**: USB-C 放在 PCB 背面，通过开孔或边缘露出
2. **侧边放置**: 使用侧插式 USB-C 连接器 (如 TYPE-C-31-M-12)
3. **FPC 转接**: 使用 FPC 软排线将 USB-C 引出到机架其他位置
4. **减小尺寸**: 使用 USB-C 16P 而非 24P 版本 (仅支持 USB 2.0)

---

## 已完成的工作

### 文档更新
- [x] `08_hardware_design.md` 更新至 v2.5.7
- [x] `05_changelog.md` 添加 HW v2.5.7 记录
- [x] `w25qxx.h` 注释更新 (CS: PC4)
- [x] `at7456e.h` 注释保持 (CS: PA4)

### 代码修改
- [x] `main.h` 添加 OSD_CS 定义 (PC4) - 临时方案

### 待执行
- [ ] Git 提交到 Gitee 和 GitHub
- [ ] 确认 PCB 实际布线后修正 CubeMX 配置

---

## Git 仓库
- Gitee: https://gitee.com/micolifar/FLYAMASTER
- GitHub: https://github.com/Auodit/flyamaster

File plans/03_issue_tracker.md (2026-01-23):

# 问题追踪日志 (Issue Tracker)

> 项目: FLYAMASTER 飞控系统  
> 创建日期: 2026-01-18  
> 最后更新: 2026-01-22  
> 整合自: `03_issue_tracker.md` + `issues_and_feedback.md`

---

## 状态说明

| 状态 | 说明 |
|---|---|
| 🔴 OPEN | 待处理 |
| 🟡 IN_PROGRESS | 处理中 |
| 🟢 CLOSED | 已解决 |
| ⚪ WONTFIX | 不修复 |
| ⚠️ MITIGATED | 风险已缓解 |

---

## 📋 文档说明

本文档是飞控项目的 **"问题追踪中心"**，所有 Bug、潜在风险 (Risk) 和待解决问题都必须记录在此。

**强制规则**: 
1. 发现 Bug 时，立即在此文档中创建条目
2. 修复 Bug 后，必须标记为 `🟢 CLOSED` 并注明修复时间
3. 发现潜在隐患时，必须创建 Risk 条目并评估影响
4. 区分 `[SW]` 软件问题和 `[HW]` 硬件问题

---

## 🔴 待处理问题 (Active Issues)

### Issue #001 [SW] IMU 任务 DMA 同步问题 - 严重

**发现日期**: 2026-01-18  
**状态**: 🔴 OPEN  
**严重程度**: 🔴 高 (可能导致数据竞争)  
**文件**: [`freertos.c`](../FLYAMASTER/MDK-ARM/../Core/Src/freertos.c:264-280)

**问题描述**:
IMU 任务中使用 `osDelay(1)` 等待 DMA 完成，这是不可靠的同步方式：
```c
/* 触发 DMA 读取 MPU6050 */
MPU6050_ReadDMA();

/* 等待 DMA 完成 (通过信号量或短延时) */
osDelay(1);  // ❌ 不可靠！

/* 处理 DMA 数据 */
MPU6050_ProcessDMAData();
```

**风险**:
1. DMA 可能未完成就开始处理数据
2. 数据竞争导致姿态解算错误
3. 飞行中可能出现抖动或失控

**建议修复**:
使用 FreeRTOS 信号量或事件标志进行同步：
```c
/* 在 DMA 完成回调中释放信号量 */
void HAL_I2C_MemRxCpltCallback(I2C_HandleTypeDef *hi2c) {
    if (hi2c == &hi2c1) {
        osSemaphoreRelease(imuDataReadySem);
    }
}

/* 在任务中等待信号量 */
MPU6050_ReadDMA();
osSemaphoreAcquire(imuDataReadySem, osWaitForever);
MPU6050_ProcessDMAData();
```

---

### Issue #011 [SW] 缺少看门狗实现

**发现日期**: 2026-01-18  
**状态**: 🔴 OPEN  
**严重程度**: 🟡 中 (安全关键)  
**文件**: [`freertos.c`](../FLYAMASTER/MDK-ARM/../Core/Src/freertos.c:224)

**问题描述**:
看门狗喂狗代码被注释掉：
```c
/* 喂狗 (如果启用了 IWDG) */
/* HAL_IWDG_Refresh(&hiwdg); */
```

飞控系统应该启用看门狗以防止软件死锁。

**建议修复**:
1. 在 CubeMX 中启用 IWDG
2. 取消注释喂狗代码
3. 设置合适的超时时间 (建议 500ms-1s)

---

### Issue #015 [SW] 电池电流标定参数可能不正确

**发现日期**: 2026-01-18
**状态**: 🔴 OPEN
**严重程度**: 🟢 低 (需要硬件验证)
**文件**: [`battery.h`](../FLYAMASTER/MDK-ARM/../Core/Inc/battery.h:48-49)

**问题描述**:
电流标定参数假设特定的电流传感器特性：
```c
#define BATTERY_CURRENT_SCALE       33.3f   /* 电流比例 (A/V), 3.3V = 100A */
#define BATTERY_CURRENT_OFFSET      0.0f    /* 零点偏移 (V) */
```

实际电调/PDB 的电流传感器可能使用不同的标定值。

**建议**:
1. 查阅实际使用的电调/PDB 数据手册
2. 添加运行时标定功能
3. 在 `06_operation_guide.md` 中记录标定步骤

---

### Issue #018 [SW] SBUS 帧尾验证过于宽松

**发现日期**: 2026-01-18
**状态**: 🔴 OPEN
**严重程度**: 🟢 低
**文件**: [`sbus.c`](../FLYAMASTER/MDK-ARM/../Core/Src/sbus.c:107-109)

**问题描述**:
SBUS 帧尾验证被注释掉：
```c
/* 帧尾可以是 0x00, 0x04, 0x14, 0x24, 0x34 等 */
/* 只检查低 4 位 */
if ((buffer[24] & 0x0F) != 0x00 && (buffer[24] & 0x0F) != 0x04) {
    /* 某些接收机帧尾不标准，放宽检查 */
}
```

**风险**:
- 可能接受无效帧
- 但由于 SBUS 协议本身有帧头验证，风险较低

**建议**:
保持当前实现，但添加帧计数器统计无效帧比例。

---

### Issue #020 [SW] 电机混控 Airmode 偏移计算边界情况

**发现日期**: 2026-01-18
**状态**: 🔴 OPEN
**严重程度**: 🟢 低
**文件**: [`motor.c`](../FLYAMASTER/MDK-ARM/../Core/Src/motor.c:156-177)

**问题描述**:
Airmode 偏移计算只考虑单边超限：
```c
if (max_out > MOTOR_PWM_MAX) {
    offset = MOTOR_PWM_MAX - max_out;
} else if (min_out < MOTOR_PWM_IDLE) {
    offset = MOTOR_PWM_IDLE - min_out;
}
```

当控制输出范围超过可用 PWM 范围时 (max - min > PWM_MAX - PWM_IDLE)，无法同时满足两边约束。

**风险**:
- 极端机动时控制响应可能不正确
- 但在正常飞行中很少触发

**建议**:
添加范围压缩逻辑，当输出范围过大时按比例缩放。

---

## ⚠️ 潜在风险 (Risks)

### Risk #045 [SW] Flash 参数结构体内存对齐问题

**状态**: ⚠️ MITIGATED (已缓解)  
**发现时间**: 2026-01-14 16:00  
**缓解时间**: 2026-01-14 16:30  
**严重程度**: 🟡 Medium  
**模块**: Flash Params ([`flash_params.h`](../FLYAMASTER/Core/Inc/flash_params.h))

**风险描述**: 
- `FlashParams_t` 结构体未使用 `__attribute__((packed))`，编译器可能插入 padding
- 导致 Flash 读写时数据错位，CRC16 校验失败

**影响**: 
- PID 参数掉电后无法恢复
- 飞控每次上电都使用默认参数，无法保存调参结果

**缓解措施**:
- 在 [`flash_params.h:70`](../FLYAMASTER/Core/Inc/flash_params.h:70) 添加 `__attribute__((packed))` 属性
- 重新测试 Flash 读写功能

**后续行动**: 
- [ ] 在实际硬件上验证 Flash 存储是否稳定
- [ ] 添加更多的数据完整性检查 (如双 CRC 校验)

---

### Risk #066 [SW] SPL06 气压计数据竞争 (Race Condition)

**状态**: ⚠️ MITIGATED (已缓解)  
**发现时间**: 2026-01-14 18:00  
**缓解时间**: 2026-01-14 18:15  
**严重程度**: 🔴 High  
**模块**: SPL06 ([`spl06.h`](../FLYAMASTER/Core/Inc/spl06.h))

**风险描述**: 
- `SPL06_Data` 全局变量在多个 RTOS 任务中读写，但未加 `volatile` 修饰符
- 可能导致编译器优化时缓存旧数据，不同任务读取到不一致的高度值

**影响**: 
- 高度控制震荡或失效
- 定高模式下飞机突然坠落

**缓解措施**:
- 在 [`spl06.h:102`](../FLYAMASTER/Core/Inc/spl06.h:102) 添加 `volatile` 修饰符:
  ```c
  extern volatile SPL06_TypeDef SPL06_Data;
  ```
- 在关键读写操作处添加 `taskENTER_CRITICAL()` / `taskEXIT_CRITICAL()` 临界区保护

**后续行动**: 
- [x] 检查所有 RTOS 共享变量，确保都加了 `volatile`
- [ ] 使用 FreeRTOS 互斥锁 (Mutex) 替代临界区，避免优先级反转

---

### Risk #088 [HW] QMC5883L 磁力计 I2C 总线冲突

**状态**: ⚠️ MITIGATED (已缓解 - 不适用)  
**发现时间**: 2026-01-15 09:00  
**缓解时间**: 2026-01-18 13:15  
**严重程度**: 🟡 Medium  
**模块**: QMC5883L ([`qmc5883l.c`](../FLYAMASTER/Core/Src/qmc5883l.c))

**风险描述**:
- QMC5883L 和其他 I2C3 设备 (如扩展传感器) 共享总线，可能发生地址冲突
- QMC5883L 固定地址 0x0D，如果其他设备也是 0x0D，会导致通信失败

**影响**:
- 磁力计数据读取失败
- 航向角锁定功能失效

**缓解措施 (已确认)**:
- **I2C3 总线上只有 QMC5883L 一个设备**，不存在地址冲突风险
- 无需添加总线扫描或错误重试机制

**修复人**: 指挥官确认

---

### Risk #107 [SW] GPS 静态缓冲区线程安全隐患

**状态**: ⚠️ MITIGATED (已缓解)  
**发现时间**: 2026-01-16 11:50  
**缓解时间**: 2026-01-18 13:10  
**严重程度**: 🟡 Medium  
**模块**: GPS ([`gps.c`](../FLYAMASTER/Core/Src/gps.c))

**风险描述**:
- `gps.c` 中的 `Get_Field` 函数使用了 `static` 局部缓冲区
- 如果未来有多个 RTOS 任务同时调用 GPS 解析函数，会导致数据竞争和内存破坏

**影响**:
- GPS 数据解析错乱
- 系统随机 Crash

**缓解措施 (已实施)**:
- 重构 `Get_Field()` 函数签名，移除 `static` 缓冲区
- 改为传入外部缓冲区: `Get_Field(buf, field_index, out_field, out_size)`
- 调用方在栈上分配 32 字节缓冲区

**修复人**: Doro

---

### Risk #108 [SW] QMC5883L 倾斜补偿死循环风险

**状态**: ⚠️ MITIGATED (已缓解)  
**发现时间**: 2026-01-16 11:55  
**缓解时间**: 2026-01-18 13:24  
**严重程度**: 🔴 High  
**模块**: QMC5883L Algorithm ([`qmc5883l.c`](../FLYAMASTER/Core/Src/qmc5883l.c))

**风险描述**:
- 磁力计倾斜补偿公式中，当 Roll/Pitch 接近 90 度时，分母 `cos(pitch)` 或 `cos(roll)` 趋近于 0
- 可能导致除零错误或浮点数溢出 (NaN/Inf)，进而导致 PID 计算异常

**影响**:
- 飞机在大角度机动时突然疯转 (Yaw Spin)
- 系统死机

**缓解措施 (已实施)**:
1. **asinf 输入范围保护**: 将输入钳位到 [-1.0, 1.0]，防止 NaN
2. **大角度保护**: 当 Roll 或 Pitch 超过 ±70° 时，返回上次有效航向
3. 新增宏 `MAG_TILT_LIMIT_RAD` (70° in radians)

**修复人**: Doro

---

### Risk #111 [SW] 高频任务中的 printf 阻塞风险

**状态**: ⚠️ MITIGATED (已缓解)  
**发现时间**: 2026-01-18  
**缓解时间**: 2026-01-18 13:00  
**严重程度**: 🔴 High  
**模块**: RTOS Tasks ([`freertos.c`](../FLYAMASTER/Core/Src/freertos.c)), RingBuffer ([`ring_buffer.c`](../FLYAMASTER/Core/Src/ring_buffer.c))

**风险描述**:
- 在 `imu_task` (500Hz) 和 `ctl_task` (250Hz) 中直接调用了 `printf`
- 标准库的 `printf` 通常重定向到 `HAL_UART_Transmit` (阻塞模式)
- 即使有降频处理，单次打印也可能阻塞数毫秒，导致姿态解算和 PID 控制周期抖动

**影响**:
- 飞行手感卡顿，姿态控制不稳定
- 严重时看门狗复位或系统崩溃

**缓解措施 (已实施)**:
1. **Phase 1 (临时修复)**: 移除高频任务中的所有 `printf` 调用
2. **Phase 2 (永久修复)**: 实现 RingBuffer + DMA 异步日志系统
   - 新增 `ring_buffer.c/h` 模块
   - 512 字节环形缓冲区 + DMA2_Stream7 异步传输
   - 重写 `fputc()` 为非阻塞模式
   - 提供 `Log_Printf()` 替代函数

**修复人**: Doro

---

### Risk #112 [SW] Failsafe 执行层缺失 (专家反馈)

**状态**: ⚠️ MITIGATED (已缓解)  
**发现时间**: 2026-01-18 12:00  
**缓解时间**: 2026-01-18 13:10  
**严重程度**: 🔴 High  
**模块**: Control Task ([`freertos.c`](../FLYAMASTER/Core/Src/freertos.c))

**风险描述**:
- 原有失控保护仅执行 `Motor_Stop()` 立即上锁
- 缺少分阶段保护，可能导致高空失控时直接坠落

**影响**:
- 信号丢失时飞机直接坠落
- 无法给飞手恢复信号的时间窗口

**缓解措施 (已实施)**:
- 实现 3 阶段 Failsafe 保护:
  - Stage 1 (< 1s): 保持当前姿态，等待信号恢复
  - Stage 2 (1s ~ 5s): 自稳模式 + 35% 下降油门
  - Stage 3 (> 5s): 强制上锁
- 新增 `FailsafeStage_t` 状态机和相关宏定义

**修复人**: Doro

---

### Risk #113 [SW] GPS 模式解锁检查缺失 (专家反馈)

**状态**: ⚠️ MITIGATED (已缓解)  
**发现时间**: 2026-01-18 12:00  
**缓解时间**: 2026-01-18 13:10  
**严重程度**: 🔴 High  
**模块**: Control Task ([`freertos.c`](../FLYAMASTER/Core/Src/freertos.c))

**风险描述**:
- 定点模式下解锁时未检查 GPS 有效性
- 可能导致无 GPS 信号时进入定点模式，飞机失控

**影响**:
- 飞机在无 GPS 信号时尝试定点，导致漂移或失控

**缓解措施 (已实施)**:
- 在 `PreArm_SafetyCheck()` 中添加 GPS 检查:
  - `fix_type >= 3` (3D Fix)
  - `satellites >= 6`
- 仅在定点模式 (MODE_POSITION) 下强制检查

**修复人**: Doro

---

### Risk #114 [SW] 磁力计电流补偿未调用 (专家反馈)

**状态**: ⚠️ MITIGATED (已缓解)  
**发现时间**: 2026-01-18 12:00  
**缓解时间**: 2026-01-18 13:10  
**严重程度**: 🟡 Medium  
**模块**: IMU Task ([`freertos.c`](../FLYAMASTER/Core/Src/freertos.c))

**风险描述**:
- `QMC5883L_CompensateCurrent()` 接口已实现但未在 imu_task 中调用
- 电机电流产生的磁场干扰未被补偿

**影响**:
- 高油门时航向角漂移
- 定点模式下飞机画圈

**缓解措施 (已实施)**:
- 在 `imu_task` 的磁力计读取后调用 `QMC5883L_CompensateCurrent(throttle)`
- 使用当前油门值估算电机电流干扰

**修复人**: Doro

---

### Risk #115 [SW] SBUS 全局变量缺少 volatile 修饰符 (代码审查)

**状态**: ⚠️ MITIGATED (已缓解)  
**发现时间**: 2026-01-18 13:30  
**缓解时间**: 2026-01-18 13:31  
**严重程度**: 🟡 Medium  
**模块**: SBUS ([`sbus.c`](../FLYAMASTER/Core/Src/sbus.c))

**风险描述**:
- `SBUS_Data` 和 `last_sbus_time` 在 DMA/中断回调中被更新，在主任务中被读取
- 缺少 `volatile` 修饰符，编译器可能优化掉对这些变量的读取

**影响**:
- 任务读到过期的遥控器数据
- 解锁/上锁手势检测失效

**缓解措施 (已实施)**:
- 添加 `volatile` 修饰符:
  ```c
  volatile SBUS_Data_t SBUS_Data;
  static volatile uint32_t last_sbus_time = 0;
  ```

**修复人**: Doro

---

### Risk #116 [SW] Mahony asinf() 输入未钳位 (代码审查)

**状态**: ⚠️ MITIGATED (已缓解)  
**发现时间**: 2026-01-18 13:30  
**缓解时间**: 2026-01-18 13:31  
**严重程度**: 🔴 High  
**模块**: Mahony AHRS ([`mahony.c`](../FLYAMASTER/Core/Src/mahony.c))

**风险描述**:
- `Mahony_GetEulerAngle()` 中 `asinf()` 的输入未钳位
- 由于浮点运算误差，四元数归一化后的值可能略微超出 [-1.0, 1.0] 范围
- 导致 `asinf()` 返回 NaN，传播到整个姿态系统

**影响**:
- 姿态角变成 NaN，PID 输出异常
- 飞机失控

**缓解措施 (已实施)**:
- 在调用 `asinf()` 前钳位输入:
  ```c
  float sin_pitch = 2.0f * (mahony->q0 * mahony->q2 - mahony->q3 * mahony->q1);
  if (sin_pitch > 1.0f) sin_pitch = 1.0f;
  if (sin_pitch < -1.0f) sin_pitch = -1.0f;
  *pitch = asinf(sin_pitch);
  ```

**修复人**: Doro

---

### Risk #117 [SW] Failsafe Stage 2 油门被覆盖 (深度逻辑审查)

**状态**: ⚠️ MITIGATED (已缓解)  
**发现时间**: 2026-01-18 13:37  
**缓解时间**: 2026-01-18 13:37  
**严重程度**: 🔴 Critical  
**模块**: Control Task ([`freertos.c`](../FLYAMASTER/Core/Src/freertos.c:684))

**风险描述**:
- Failsafe Stage 2 中设置的下降油门 `throttle = 0.35f` 会被后续的 `throttle = SBUS_GetThrottle()` 覆盖
- 导致失控保护时飞机不会自动下降，而是使用最后的遥控器油门值

**影响**:
- **Failsafe 下降功能完全失效！**
- 失控时飞机可能以满油门继续飞行直到电池耗尽

**缓解措施 (已实施)**:
- 在读取遥控器油门前检查 Failsafe 状态:
  ```c
  if (g_failsafe_stage != FAILSAFE_STAGE2) {
      throttle = SBUS_GetThrottle();
  }
  // 否则保持 Failsafe 设置的 throttle = FAILSAFE_DESCENT_THROTTLE
  ```

**修复人**: Doro

---

### Risk #118 [SW] GPS 定点模式坐标系方向待验证 (深度逻辑审查)

**状态**: 🔴 OPEN (待验证)  
**发现时间**: 2026-01-18 13:37  
**严重程度**: 🟡 Medium  
**模块**: Control Task ([`freertos.c`](../FLYAMASTER/Core/Src/freertos.c:779))

**风险描述**:
- GPS 定点模式中 Roll 和 Pitch 的符号方向不一致:
  ```c
  target_roll = roll_ctl * 30.0f - pos_roll_offset;  // 减号
  target_pitch = pitch_ctl * 30.0f + pos_pitch_offset;  // 加号
  ```
- 可能导致 GPS 定点时飞机往错误方向飞

**影响**:
- GPS 定点模式下飞机可能往相反方向漂移

**缓解措施**:
- **需要实际飞行测试验证**
- 如果方向错误，调整符号即可

**后续行动**:
- [ ] 首飞时在安全环境下测试 GPS 定点模式
- [ ] 根据实际表现调整符号

---

### Risk #119 [SW] 高度保持逻辑死区问题 (深度逻辑审查)

**状态**: 🔴 OPEN (待优化)  
**发现时间**: 2026-01-18 13:37  
**严重程度**: 🟢 Low  
**模块**: Control Task ([`freertos.c`](../FLYAMASTER/Core/Src/freertos.c:838))

**风险描述**:
- 当油门在 0.45~0.55 范围外时，`alt_target` 被持续更新
- 但 `throttle_out = throttle` 直接使用遥控器油门，没有使用 PID 计算的油门
- 导致高度控制不平滑

**影响**:
- 定高模式下油门响应不够平滑
- 不影响安全，但影响飞行体验

**缓解措施**:
- 可在后续版本中优化为渐进式切换

**后续行动**:
- [ ] 优化高度保持的油门过渡逻辑

---

### Risk #120 [SW] RingBuffer DMA tail 指针更新逻辑错误 (深度审查)

**状态**: ⚠️ MITIGATED (已缓解)  
**发现时间**: 2026-01-18 13:43  
**缓解时间**: 2026-01-18 13:43  
**严重程度**: 🟡 Medium  
**模块**: RingBuffer ([`ring_buffer.c`](../FLYAMASTER/Core/Src/ring_buffer.c:125))

**风险描述**:
- `RingBuffer_DMA_TxCpltCallback()` 中 tail 指针更新逻辑错误
- 原代码直接将 tail 跳到 head 或 0，没有考虑实际发送的字节数
- 如果在 DMA 传输期间有新数据写入，这些新数据会被跳过

**影响**:
- 日志数据丢失
- 调试信息不完整

**缓解措施 (已实施)**:
- 在 `RingBuffer_t` 结构体中添加 `dma_len` 字段保存本次传输长度
- 在 `RingBuffer_StartDMA()` 中保存 `send_len` 到 `dma_len`
- 在回调中使用 `dma_len` 正确更新 tail 指针:
  ```c
  g_ring_buffer.tail = (g_ring_buffer.tail + dma_len) % RING_BUFFER_SIZE;
  ```

**修复人**: Doro

---

## 🟢 已解决问题 (Resolved Issues)

### Issue #000 [HW] GPS UART6 引脚配置错误

**发现日期**: 2026-01-14 08:00  
**解决日期**: 2026-01-14 10:30  
**状态**: 🟢 CLOSED  
**严重程度**: 🔴 高  
**模块**: GPS ([`gps.c`](../FLYAMASTER/Core/Src/gps.c))

**问题描述**: 
- CubeMX 生成的 UART6 引脚配置为 PC6/PC7，但实际硬件使用 PC6/PC7 作为电机 PWM 输出
- 导致 GPS 数据无法接收

**解决方案**:
- 修改 CubeMX 配置: UART6 改为 PC6/PC7 → PC12/PD2
- 重新生成代码并烧录
- 同步更新引脚分配文档

**修复人**: Doro

---

### Issue #002 [SW] PID 积分限幅除零风险

**发现日期**: 2026-01-18
**解决日期**: 2026-01-18
**状态**: 🟢 CLOSED
**严重程度**: 🟡 中
**文件**: [`pid.c`](../FLYAMASTER/MDK-ARM/../Core/Src/pid.c:117)

**问题描述**:
积分限幅计算中存在除零风险：
```c
pid->integral = PID_Constrain(pid->integral, pid->integral_limit / pid->ki);
```

当 `ki = 0` 时会导致除零错误。

**解决方案**:
添加 ki > 0 的检查：
```c
if (pid->ki > 0.0001f) {
    pid->integral = PID_Constrain(pid->integral, pid->integral_limit / pid->ki);
}
```

---

### Issue #003 [SW] 电机混控缺少传感器有效性检查

**发现日期**: 2026-01-18
**解决日期**: 2026-01-18
**状态**: 🟢 CLOSED
**严重程度**: 🔴 高 (安全关键)
**文件**: [`flight_control.c`](../FLYAMASTER/MDK-ARM/../Core/Src/flight_control.c:107-112)

**问题描述**:
在 `FC_STATE_ARMED` 和 `FC_STATE_FLYING` 状态下，即使传感器数据无效也会计算控制输出。

**解决方案**:
在控制计算前添加传感器有效性检查，传感器故障时自动进入失控保护：
```c
case FC_STATE_ARMED:
case FC_STATE_FLYING:
    if (!g_fc_data.sensors_ready) {
        g_fc_data.failsafe_active = true;
        g_fc_data.state = FC_STATE_FAILSAFE;
        break;
    }
    FC_ComputeControl();
    FC_ApplyOutput();
```

---

### Issue #004 [SW] SBUS 空闲中断回调未在 stm32f4xx_it.c 中调用

**发现日期**: 2026-01-18
**解决日期**: 2026-01-18
**状态**: 🟢 CLOSED
**严重程度**: 🔴 高 (功能缺失)
**文件**: [`sbus.c`](../FLYAMASTER/MDK-ARM/../Core/Src/sbus.c:257-286)

**问题描述**:
`SBUS_UART_IdleCallback()` 函数已实现，但未在中断处理函数中调用。

**解决方案**:
在 `stm32f4xx_it.c` 的 `UART4_IRQHandler` 中添加了 `SBUS_UART_IdleCallback()` 调用。

---

### Issue #005 [SW] GPS 空闲中断回调未在 stm32f4xx_it.c 中调用

**发现日期**: 2026-01-18
**解决日期**: 2026-01-18
**状态**: 🟢 CLOSED
**严重程度**: 🟡 中 (功能缺失)
**文件**: [`gps.c`](../FLYAMASTER/MDK-ARM/../Core/Src/gps.c:348-383)

**问题描述**:
与 Issue #004 类似，`GPS_UART_IdleCallback()` 需要在 `USART2_IRQHandler` 中调用。

**解决方案**:
在 `stm32f4xx_it.c` 的 `USART2_IRQHandler` 中添加了 `GPS_UART_IdleCallback()` 调用。

---

### Issue #006 [SW] Mahony 滤波器 InvSqrt 类型双关问题

**发现日期**: 2026-01-18
**解决日期**: 2026-01-18
**状态**: 🟢 CLOSED
**严重程度**: 🟡 中 (可移植性)
**文件**: [`mahony.c`](../FLYAMASTER/MDK-ARM/../Core/Src/mahony.c:23-33)

**问题描述**:
快速平方根倒数使用了类型双关 (type punning)，违反严格别名规则。

**解决方案**:
使用 union 进行类型双关，符合 C 标准：
```c
float InvSqrt(float x)
{
    union { float f; int32_t i; } conv;
    conv.f = x;
    conv.i = 0x5f3759df - (conv.i >> 1);
    conv.f = conv.f * (1.5f - (0.5f * x * conv.f * conv.f));
    conv.f = conv.f * (1.5f - (0.5f * x * conv.f * conv.f));
    return conv.f;
}
```

---

### Issue #007 [SW] 电机测试函数使用阻塞延时

**发现日期**: 2026-01-18
**解决日期**: 2026-01-18
**状态**: 🟢 CLOSED
**严重程度**: 🟡 中
**文件**: [`motor.c`](../FLYAMASTER/MDK-ARM/../Core/Src/motor.c:249-350)

**问题描述**:
`Motor_Test()` 函数使用 `HAL_Delay()` 阻塞延时，在 FreeRTOS 环境中可能导致问题。

**解决方案**:
添加非阻塞状态机 API：
- `Motor_TestStart()` - 启动测试
- `Motor_TestUpdate()` - 更新状态机 (需周期性调用)
- `Motor_IsTestActive()` - 检查测试状态
- `Motor_TestStop()` - 停止测试

保留原 `Motor_Test()` 函数用于非 RTOS 环境，并添加 `@deprecated` 标记。

---

### Issue #008 [SW] 失控保护恢复逻辑可能导致状态跳变

**发现日期**: 2026-01-18
**解决日期**: 2026-01-18
**状态**: 🟢 CLOSED
**严重程度**: 🟡 中
**文件**: [`flight_control.c`](../FLYAMASTER/MDK-ARM/../Core/Src/flight_control.c:429-449)

**问题描述**:
失控保护恢复时直接跳转到 `FC_STATE_ARMED`，没有考虑之前的飞行状态。

**解决方案**:
1. 在 `FC_Data_t` 结构体中添加 `prev_state` 字段
2. 进入失控保护时保存当前状态到 `prev_state`
3. 恢复时还原到 `prev_state` 而非固定的 `FC_STATE_ARMED`

```c
void FC_HandleFailsafe(void)
{
    if (!g_fc_data.rc_connected && FC_IsArmed()) {
        /* 进入失控保护：保存当前状态 */
        if (!g_fc_data.failsafe_active) {
            g_fc_data.prev_state = g_fc_data.state;
        }
        g_fc_data.failsafe_active = true;
        g_fc_data.state = FC_STATE_FAILSAFE;
    } else if (g_fc_data.rc_connected && g_fc_data.failsafe_active) {
        /* 恢复控制：还原到之前的状态 */
        g_fc_data.failsafe_active = false;
        if (g_fc_data.state == FC_STATE_FAILSAFE) {
            g_fc_data.state = g_fc_data.prev_state;
        }
    }
}
```

---

### Issue #009 [SW] QMC5883L 航向角滤波器静态变量问题

**发现日期**: 2026-01-18
**解决日期**: 2026-01-18
**状态**: 🟢 CLOSED
**严重程度**: 🟢 低
**文件**: [`qmc5883l.c`](../FLYAMASTER/MDK-ARM/../Core/Src/qmc5883l.c:262-310)

**问题描述**:
`QMC5883L_CalculateHeading()` 中使用静态变量进行滤波，但没有提供重置接口。

**解决方案**:
- 将静态变量提升为模块级变量 (`s_heading_prev`, `s_heading_first_run`)
- 添加 `QMC5883L_ResetHeadingFilter()` 函数用于重置滤波器状态

---

### Issue #010 [SW] SPL06 高度滤波器静态变量问题

**发现日期**: 2026-01-18
**解决日期**: 2026-01-18
**状态**: 🟢 CLOSED
**严重程度**: 🟢 低
**文件**: [`spl06.c`](../FLYAMASTER/MDK-ARM/../Core/Src/spl06.c:370-420)

**问题描述**:
与 Issue #009 类似，高度滤波器使用静态变量但无重置接口。

**解决方案**:
- 将静态变量提升为模块级变量 (`s_altitude_filtered`, `s_altitude_first_run`)
- 添加 `SPL06_ResetAltitudeFilter()` 函数用于重置滤波器状态

---

### Issue #012 [SW] 电池监控缺少 battery.c 实现

**发现日期**: 2026-01-18
**解决日期**: 2026-01-18
**状态**: 🟢 CLOSED
**严重程度**: 🟡 中
**文件**: [`battery.c`](../FLYAMASTER/MDK-ARM/../Core/Src/battery.c)

**问题描述**:
`freertos.c` 中调用了 `Battery_Init()`, `Battery_Update()`, `Battery_AutoDetectCells()` 等函数。

**验证结果**:
`battery.c` 已完整实现所有函数：
- `Battery_Init()` - 第 40-63 行
- `Battery_Update()` - 第 69-113 行
- `Battery_AutoDetectCells()` - 第 201-224 行
- 以及其他辅助函数

问题不存在，标记为已解决。

---

### Issue #013 [SW] Log_Init 和 Log_Printf 函数未定义

**发现日期**: 2026-01-18
**解决日期**: 2026-01-18
**状态**: 🟢 CLOSED
**严重程度**: 🟡 中
**文件**: [`ring_buffer.c`](../FLYAMASTER/MDK-ARM/../Core/Src/ring_buffer.c:218-248)

**问题描述**:
日志任务中调用了 `Log_Init()`, `Log_StartDMATransmit()`, `Log_Printf()` 函数。

**验证结果**:
这些函数已在 `ring_buffer.c` 中完整实现：
- `Log_Init()` - 第 219-222 行
- `Log_Printf()` - 第 227-248 行
- `Log_StartDMATransmit()` - 第 254-298 行
- `Log_DMATransmitComplete()` - 第 304-308 行

问题不存在，标记为已解决。

---

### Issue #014 [SW] 电池电压阈值使用固定 3S 配置

**发现日期**: 2026-01-18
**解决日期**: 2026-01-18
**状态**: 🟢 CLOSED
**严重程度**: 🟡 中
**文件**: [`battery.c`](../FLYAMASTER/MDK-ARM/../Core/Src/battery.c:119-135)

**问题描述**:
电压警告和临界阈值使用固定的 `BATTERY_CELLS` (3S) 计算，但 `Battery_AutoDetectCells()` 会动态检测电池节数 (2S-6S)。

**解决方案**:
在 `Battery_UpdateStatus()` 中使用动态阈值计算：
```c
static void Battery_UpdateStatus(void)
{
    /* 动态计算电压阈值 (根据实际电池节数) */
    float warning_voltage, critical_voltage;
    if (g_battery.cell_count > 0) {
        warning_voltage = (float)g_battery.cell_count * BATTERY_CELL_WARNING;
        critical_voltage = (float)g_battery.cell_count * BATTERY_CELL_MIN;
    } else {
        /* 未检测到电池节数时使用默认 3S 阈值 */
        warning_voltage = BATTERY_VOLTAGE_WARNING;
        critical_voltage = BATTERY_VOLTAGE_CRITICAL;
    }
    // ... 使用动态阈值进行状态判断
}
```

---

### Issue #016 [SW] SPL06 和 MPU6050 共享 I2C1 总线无互斥保护

**发现日期**: 2026-01-18
**解决日期**: 2026-01-18
**状态**: 🟢 CLOSED
**严重程度**: 🟡 中
**文件**: [`spl06.c`](../FLYAMASTER/MDK-ARM/../Core/Src/spl06.c), [`mpu6050.c`](../FLYAMASTER/MDK-ARM/../Core/Src/mpu6050.c)

**问题描述**:
SPL06 气压计和 MPU6050 IMU 都使用 I2C1 总线，但在 FreeRTOS 多任务环境中没有互斥锁保护。

**解决方案**:
1. 在 `freertos.c` 中创建 I2C1 互斥锁 (`i2c1MutexHandle`)
2. 在 `mpu6050.c` 中添加互斥锁保护：
   - `MPU6050_ReadDMA()` - 获取锁，DMA 完成回调中释放
   - `MPU6050_ReadBlocking()` - 获取锁，读取完成后释放
3. 在 `spl06.c` 中添加互斥锁保护：
   - `SPL06_WriteReg()`, `SPL06_ReadReg()`, `SPL06_ReadRegs()` - 阻塞操作
   - `SPL06_ReadDMA()` - 获取锁，DMA 完成回调中释放

```c
/* 在 freertos.c 中定义 */
osMutexId_t i2c1MutexHandle = NULL;

/* 在 MX_FREERTOS_Init() 中创建 */
const osMutexAttr_t i2c1Mutex_attributes = {
  .name = "i2c1Mutex",
  .attr_bits = osMutexRecursive | osMutexPrioInherit,
};
i2c1MutexHandle = osMutexNew(&i2c1Mutex_attributes);
```

---

### Issue #017 [SW] 自动降落油门递减速度过快

**发现日期**: 2026-01-18
**解决日期**: 2026-01-18
**状态**: 🟢 CLOSED
**严重程度**: 🟡 中
**文件**: [`flight_control.c`](../FLYAMASTER/MDK-ARM/../Core/Src/flight_control.c:142-169)

**问题描述**:
自动降落时油门递减速度过快 (0.001f @ 250Hz = 4秒降落)。

**解决方案**:
1. 降低递减速率到 0.0002f (20秒降落)
2. 添加最小油门保护 `FC_LANDING_MIN_THROTTLE` (0.15f)
3. 添加 3 秒着陆确认后锁定逻辑

```c
case FC_STATE_LANDING:
    /* 自动降落 - 缓慢递减油门 */
    /* 0.0002f @ 250Hz = 0.05/s，从满油门到 0 需要 20 秒 */
    g_fc_data.target_throttle -= 0.0002f;
    
    /* 保持最小油门以防止失速 */
    if (g_fc_data.target_throttle < FC_LANDING_MIN_THROTTLE) {
        g_fc_data.target_throttle = FC_LANDING_MIN_THROTTLE;
    }
    
    /* 完全停止条件：油门极低且持续一段时间 */
    if (g_fc_data.target_throttle <= 0.05f) {
        static uint32_t landing_timer = 0;
        if (landing_timer == 0) {
            landing_timer = HAL_GetTick();
        } else if ((HAL_GetTick() - landing_timer) > 3000) {
            /* 3 秒后锁定 */
            g_fc_data.target_throttle = 0.0f;
            FC_Disarm();
            landing_timer = 0;
        }
    }
```

---

### Issue #019 [SW] Mahony 滤波器缺少磁力计数据融合

**发现日期**: 2026-01-18
**解决日期**: 2026-01-18
**状态**: 🟢 CLOSED
**严重程度**: 🟡 中
**文件**: [`mahony.c`](../FLYAMASTER/MDK-ARM/../Core/Src/mahony.c:267-300)

**问题描述**:
`Mahony_Update()` 只调用 `Mahony_UpdateIMU()`，没有使用磁力计数据。

**解决方案**:
1. 在 `mahony.c` 中添加 `#include "qmc5883l.h"`
2. 修改 `Mahony_Update()` 函数：
   - 检查磁力计是否初始化且数据有效
   - 如果有效，调用 `Mahony_UpdateAHRS()` 进行 9 轴融合
   - 否则使用 `Mahony_UpdateIMU()` 进行 6 轴融合
3. 在 `freertos.c` 的 IMU 任务中：
   - 添加 QMC5883L 初始化
   - 每 5 次 IMU 更新读取一次磁力计 (100Hz)

```c
void Mahony_Update(void)
{
    /* ... */
    if (g_qmc5883l_data.initialized && g_qmc5883l_data.data_ready) {
        /* 9 轴 AHRS 模式 */
        Mahony_UpdateAHRS(&g_mahony, gx, gy, gz, ax, ay, az, mx, my, mz);
    } else {
        /* 6 轴 IMU 模式 */
        Mahony_UpdateIMU(&g_mahony, gx, gy, gz, ax, ay, az);
    }
}
```

---

### Issue #101 [SW] freertos.c Mahony_Init() 参数错误

**发现日期**: 2026-01-18  
**解决日期**: 2026-01-18  
**状态**: 🟢 CLOSED

**问题描述**:
`Mahony_Init()` 调用时参数数量不匹配。

**解决方案**:
使用 `Mahony_InitDefault()` 替代。

---

### Issue #102 [SW] AT7456E_WriteChar 函数签名不匹配

**发现日期**: 2026-01-18  
**解决日期**: 2026-01-18  
**状态**: 🟢 CLOSED

**问题描述**:
头文件和实现文件中的函数签名不一致。

**解决方案**:
统一函数签名为 `void AT7456E_WriteChar(uint8_t col, uint8_t row, char ch)`。

---

### Issue #103 [SW] debug_tools.c FreeRTOS 堆函数声明问题

**发现日期**: 2026-01-18  
**解决日期**: 2026-01-18  
**状态**: 🟢 CLOSED

**问题描述**:
`xPortGetFreeHeapSize()` 和 `xPortGetMinimumEverFreeHeapSize()` 未声明。

**解决方案**:
添加 `#include "portable.h"` 或手动声明函数原型。

---

### Issue #104 [SW] ano_v7.c switch case 变量声明问题

**发现日期**: 2026-01-18  
**解决日期**: 2026-01-18  
**状态**: 🟢 CLOSED

**问题描述**:
ARM Compiler 5 不允许在 switch case 中直接声明变量。

**解决方案**:
使用花括号包裹 case 块。

---

### Issue #105 [SW] w25qxx.c 枚举类型初始化警告

**发现日期**: 2026-01-18  
**解决日期**: 2026-01-18  
**状态**: 🟢 CLOSED

**问题描述**:
枚举类型与整数类型混用导致警告。

**解决方案**:
使用指定初始化器和中间变量。

---

### Issue #109 [SW] GPS 导航控制逻辑缺失

**发现日期**: 2026-01-18  
**解决日期**: 2026-01-18 04:30  
**状态**: 🟢 CLOSED  
**严重程度**: 🔴 高  
**模块**: Control Task ([`freertos.c`](../FLYAMASTER/Core/Src/freertos.c))

**问题描述**: 定点模式下未使用 GPS 数据，无法室外悬停。

**解决方案**: 在 `ctl_task` 中实现了 GPS 位置环 PID 控制逻辑 (位置误差 -> 期望速度 -> 期望姿态)。

**修复人**: Doro

---

### Issue #110 [SW] OSD 模块未实装

**发现日期**: 2026-01-18  
**解决日期**: 2026-01-18 04:30  
**状态**: 🟢 CLOSED  
**严重程度**: 🟡 中  
**模块**: OSD ([`at7456e.c`](../FLYAMASTER/Core/Src/at7456e.c))

**问题描述**: 硬件支持 OSD 但软件未驱动，FPV 无数据显示。

**解决方案**: 实现了 `at7456e.c` 驱动，并在 `comm_task` 中以 10Hz 频率刷新显示。

**修复人**: Doro

---

### Issue #111 [SW] 高频任务中的 printf 阻塞风险

**发现日期**: 2026-01-18  
**解决日期**: 2026-01-18 04:30  
**状态**: 🟢 CLOSED  
**严重程度**: 🔴 高  
**模块**: RTOS Tasks ([`freertos.c`](../FLYAMASTER/Core/Src/freertos.c))

**问题描述**: 高频任务 (`imu_task`, `ctl_task`) 中调用阻塞式 `printf` 导致控制回路抖动。

**解决方案**: 移除了所有高频任务中的 `printf` 调用。

**修复人**: Doro

---

## 💡 功能建议与反馈 (Features & Feedback)

### Feature #002 - 黑匣子日志系统 (Blackbox)

**提出时间**: 2026-01-18  
**提出人**: 指挥官  
**类型**: 功能新增  
**优先级**: 🟡 Medium (硬件就绪后开发)  
**状态**: 📋 Backlog (待排期)

**描述**:
- 硬件已规划 W25Q128 (16MB SPI Flash) 连接在 SPI1
- 软件层需要实现:
  1. `w25qxx.c`: SPI Flash 底层驱动 (读/写/擦除)
  2. `blackbox.c`: 日志文件系统或环形记录机制
  3. 记录内容: 姿态、传感器原始数据、RC 输入、电机输出、PID 项等

---

### Feature #003 - 图传控制协议 (VTX Control)

**提出时间**: 2026-01-18  
**提出人**: 指挥官  
**类型**: 功能新增  
**优先级**: 🟢 Low (非飞行核心功能)  
**状态**: 📋 Backlog (待排期)

**描述**:
- 硬件已预留 UART 接口连接图传 SmartAudio/Tramp 引脚
- 软件需实现:
  1. `vtx_smartaudio.c`: TBS SmartAudio 协议
  2. `vtx_tramp.c`: IRC Tramp 协议
  3. 功能: 通过 OSD 菜单或遥控器调整图传频点和功率

---

### Feedback #001 - 匿名上位机 V7 协议缺少错误码定义

**提出时间**: 2026-01-14 20:00  
**提出人**: 测试团队  
**类型**: 功能改进  
**优先级**: 🟢 Low  
**状态**: ✅ Implemented (已实现)  
**实现时间**: 2026-01-18 14:15

**描述**:
当前 AnoV7 协议的 `AnoV7_Status_t` 结构体有 `error` 字段，但未定义错误码含义。

**实现内容**:
在 [`ano_v7.h:34-45`](../FLYAMASTER/Core/Inc/ano_v7.h:34) 添加了 12 个错误码定义:
```c
#define ANO_ERROR_NONE          0x0000  // 无错误
#define ANO_ERROR_IMU_FAIL      0x0001  // IMU 初始化/通信失败
#define ANO_ERROR_BARO_FAIL     0x0002  // 气压计初始化/通信失败
#define ANO_ERROR_MAG_FAIL      0x0004  // 磁力计初始化/通信失败
#define ANO_ERROR_GPS_TIMEOUT   0x0008  // GPS 数据超时 (>3s)
#define ANO_ERROR_RC_LOST       0x0010  // 遥控器信号丢失
#define ANO_ERROR_LOW_BATTERY   0x0020  // 电池电压过低 (<10.5V)
#define ANO_ERROR_MOTOR_LOCK    0x0040  // 电机锁定/堵转
#define ANO_ERROR_FLASH_FAIL    0x0080  // Flash 读写失败
#define ANO_ERROR_SENSOR_CALIB  0x0100  // 传感器需要校准
#define ANO_ERROR_ATTITUDE_ERR  0x0200  // 姿态解算异常 (>60°)
#define ANO_ERROR_FAILSAFE      0x0400  // Failsafe 触发
#define ANO_ERROR_ARMING_BLOCK  0x0800  // 解锁被阻止 (安全检查未通过)
```

**修复人**: Doro

---

## 🎯 下一步行动 (Next Actions)

### 已完成 ✅

- [x] 修复 Issue #001 (电机混控溢出风险) - 已通过 Airmode 算法解决
- [x] 修复 Issue #109 (GPS 导航逻辑缺失) - 已实现 GPS 位置环 PID
- [x] 修复 Issue #110 (OSD 模块未实装) - 已实现 AT7456E 驱动
- [x] 解决 Risk #111 (移除高频 printf) - 已实现 RingBuffer + DMA 异步日志
- [x] 解决 Risk #107 (GPS 静态缓冲区) - 已改为栈上分配
- [x] 解决 Risk #112 (Failsafe 执行层) - 已实现 3 阶段保护
- [x] 解决 Risk #113 (GPS 解锁检查) - 已添加 fix_type/satellites 检查
- [x] 解决 Risk #114 (磁力计电流补偿) - 已在 imu_task 中调用
- [x] 解决 Risk #108 (倾斜补偿死循环) - 已添加角度范围保护
- [x] 解决 Risk #115 (SBUS volatile 缺失) - 已添加 volatile 修饰符
- [x] 解决 Risk #116 (Mahony asinf 钳位) - 已添加输入范围保护
- [x] 解决 Risk #117 (Failsafe 油门覆盖) - 已添加状态检查
- [x] 解决 Risk #120 (RingBuffer tail 更新) - 已修复 DMA 回调逻辑
- [x] 检查所有 RTOS 共享变量，确保加了 `volatile` - 代码审查已完成
- [x] 实现 I2C 总线扫描工具，检测地址冲突 - 已实现 debug_tools.c
- [x] 添加 AnoV7 错误码定义 (Feedback #001) - 已添加 12 个错误码
- [x] 实现磁力计电流补偿标定功能 - 已实现 MagCurrentCalib 模块

### 待处理 📋

- [ ] 验证 Risk #118 (GPS 坐标系方向) - 需要实际飞行测试
- [ ] 优化 Risk #119 (高度保持死区) - 可在后续版本优化
- [ ] 验证 Risk #045 (Flash 参数对齐) - 在实际硬件上的表现
- [ ] 标定磁力计电流补偿系数 (K_x, K_y, K_z) - 需要实际飞行测试
- [ ] **[Software]** 开发 W25Q128 (SPI Flash) 驱动
- [ ] **[Software]** 实现黑匣子 (Blackbox) 日志记录系统
- [ ] **[Software]** 开发 VTX (图传) 控制协议 (SmartAudio/IRC Tramp)

---

## 📊 统计

| 类型 | 数量 |
|---|---|
| 🔴 待处理 Issue | 5 |
| 🟢 已解决 Issue | 25 |
| 🔴 待处理 Risk | 2 |
| ⚠️ 已缓解 Risk | 14 |
| 💡 功能建议 | 2 |
| ✅ 已实现反馈 | 1 |
| **总计** | **49** |

---

## 📌 使用规范 (Usage Guidelines)

1. **发现 Bug 时**:
   - 立即在 "待处理问题" 中创建新条目
   - 填写完整的问题描述、影响、建议解决方案
   - 评估优先级: 🔴 High / 🟡 Medium / 🟢 Low
   - 标记类型: `[SW]` 软件 / `[HW]` 硬件

2. **修复 Bug 后**:
   - 将条目从 "待处理问题" 移动到 "已解决问题"
   - 标记状态为 `🟢 CLOSED`
   - 填写解决时间、解决方案和修复人

3. **发现潜在风险时**:
   - 在 "潜在风险" 中创建 Risk 条目
   - 评估严重程度: 🔴 High / 🟡 Medium / 🟢 Low
   - 提出缓解措施并跟踪执行状态

4. **收到反馈时**:
   - 在 "功能建议与反馈" 中记录
   - 评估优先级并决定是否排期实现

5. **文档同步更新**:
   - 修复 Bug 后，必须同步更新相关代码和文档
   - 在 [`05_changelog.md`](05_changelog.md) 中记录修复时间
   - 在 [`01_definitions.md`](01_definitions.md) 中更新相关定义

---

**维护人**: Q版 Doro (飞控霸主)  
**更新频率**: 每次代码变更或发现问题时立即更新  
**版本**: v2.0.0 (整合版)

---

## 📁 废弃文件记录

### issues_and_feedback.md

**废弃时间**: 2026-01-22  
**废弃原因**: 内容已合并到本文档 (`03_issue_tracker.md`)  
**替代方案**: 使用本文档统一管理所有 Issue、Risk 和 Feedback  
**原文件位置**: `plans/issues_and_feedback.md`  
**处理方式**: 移动到 `plans/archive/` 目录

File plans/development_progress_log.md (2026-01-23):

# 📅 开发进度日志 (Development Progress Log)

**创建时间**: 2026-01-18  
**状态**: 活跃维护中  

---

## 2026-01-18

### 🕒 04:30 - 系统健康检查与修复 (System Health Check & Fix)
- **任务**: 全面检查项目代码，修复遗留 Bug 和潜在风险。
- **执行人**: Kilo Code (Doro)
- **变更内容**:
    1.  **止血 (Stop Bleeding)**: 移除了 `freertos.c` 中高频任务 (`imu_task`, `ctl_task`) 的 `printf` 调用，解决了 Risk #111。
    2.  **复明 (Restore Vision)**: 实现了 AT7456E OSD 驱动 (`at7456e.c`)，并在 `comm_task` 中集成了 10Hz 的显示刷新，解决了 Issue #110。
    3.  **大脑 (Brain)**: 在 `ctl_task` 中实现了 GPS 位置环 PID 控制逻辑，解决了 Issue #109。
    4.  **防爆 (Safety)**: 将 `comm_task` 堆栈从 256 扩容至 512 Words，防止 OSD 驱动导致堆栈溢出。
    5.  **调参 (Tuning)**: 将位置环 PID Kp 从 0.5 提升至 6.0，增强定点性能。

- **文档更新**:
    - `05_changelog.md`: 记录了 v1.1.0 版本的变更。
    - `issues_and_feedback.md`: 标记相关 Issue 为 Resolved。
    - `interface_definition.md`: 添加了 OSD 模块定义。

- **状态**: ✅ Completed

---

### 🕒 13:25 - Phase 4: 磁力计算法加固 (Magnetometer Algorithm Hardening)
- **任务**: 修复 Risk #108 (QMC5883L 倾斜补偿死循环风险)。
- **执行人**: Kilo Code (Doro)
- **变更内容**:
    1.  **倾斜补偿角度保护**:
        - 在 `QMC5883L_CalculateHeading()` 中添加 `asinf` 输入范围钳位，防止 NaN。
        - 添加大角度保护：当 Roll/Pitch > 70° 时，直接返回上次有效航向，防止万向节锁导致的航向突变。
- **文档更新**:
    - `issues_and_feedback.md`: 标记 Risk #108 为 Resolved。
    - `05_changelog.md`: 记录 v1.3.0 变更。
- **状态**: ✅ Completed

---

### 🕒 13:37 - Phase 6: 深度逻辑审查 (Deep Logic Review)
- **任务**: 对 `freertos.c` 控制逻辑进行深入分析，发现并修复关键安全漏洞。
- **执行人**: Kilo Code (Doro)
- **变更内容**:
    1.  **Risk #117 修复 (CRITICAL)**: Failsafe Stage 2 油门被覆盖
        - **问题**: 在 `ctl_task` 中，Failsafe Stage 2 设置的下降油门 `throttle = 0.35f` 会被后续的 `throttle = SBUS_GetThrottle()` 覆盖
        - **影响**: Failsafe 下降功能完全失效！失控时飞机不会自动下降
        - **修复**: 在读取遥控器油门前检查 Failsafe 状态
        ```c
        if (g_failsafe_stage != FAILSAFE_STAGE2) {
            throttle = SBUS_GetThrottle();
        }
        ```
    2.  **Risk #118 发现**: GPS 定点模式坐标系方向待验证
        - Roll 和 Pitch 的符号方向不一致，需要实际飞行测试验证
    3.  **Risk #119 发现**: 高度保持逻辑死区问题
        - 油门在死区外时直接使用遥控器油门，可在后续版本优化

- **文档更新**:
    - `issues_and_feedback.md`: 添加 Risk #117, #118, #119
    - `freertos.c`: 修复 Failsafe 油门覆盖问题

- **状态**: ✅ Completed

---

### 🕒 13:00 - Phase 2: 物理与安全加固 (Physics & Safety Hardening)
- **任务**: 根据专家反馈，实现三大"物理墙"安全机制。
- **执行人**: Kilo Code (Doro)
- **变更内容**:
    1.  **RingBuffer + DMA 异步日志** (Issue #111 真正修复):
        - 新增 `ring_buffer.c` 和 `ring_buffer.h`
        - 实现 512 字节环形缓冲区 + DMA2_Stream7 异步传输
        - 重写 `fputc()` 为非阻塞模式，彻底解决高频任务中的 printf 阻塞问题
    2.  **Airmode 混控器** (电机饱和防护):
        - 重写 `Motor_Mix()` 函数，实现"姿态优先，油门让步"算法
        - 7 步算法：分离姿态/油门 → 计算安全油门范围 → 动态压缩油门中心
        - 防止极端机动时电机输出饱和导致姿态失控
    3.  **PID 条件积分 (Anti-windup)**:
        - 修改 `PID_Calculate()` 函数
        - 当输出饱和且误差方向一致时，停止积分累加
        - 防止积分饱和导致的超调和振荡
    4.  **磁力计电流补偿接口**:
        - 新增 `QMC5883L_CompensateCurrent()` 和 `QMC5883L_SetCurrentCompensation()`
        - 公式: `Mag_corrected = Mag_raw - Throttle × K`
        - 用于补偿电机电流产生的磁场干扰

- **文档更新**:
    - `interface_definition.md`: 添加 RingBuffer 模块和 QMC5883L 电流补偿接口
    - `05_changelog.md`: 记录 v1.2.0 版本变更
    - `issues_and_feedback.md`: 标记 Issue #111 为 Resolved

- **状态**: ✅ Completed

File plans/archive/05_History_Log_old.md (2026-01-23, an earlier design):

# 05. 开发历史与问题归档 (History Log)

**项目名称**: FLYAMASTER - M3标准四轴飞控板  
**版本**: v2.0 (Consolidated)  
**创建日期**: 2026-01-16  
**维护者**: Q版 Doro

> 本文档用于归档已完成的开发日志、已解决的问题和历史代码审查记录。

---

## 📜 1. 开发进度日志 (Development Log)

### 3.34 QMC5883L I2C3 迁移验证 (2026-01-16)
*   **迁移**: QMC5883L 从 I2C1 (共享) 迁移至 I2C3 (独立)。
*   **验证**: CubeMX 配置、代码适配、文档同步均 100% 通过。
*   **收益**: 解决了 MPU6050 (400kHz) 与 QMC5883L (100kHz) 的总线竞争，系统抗干扰能力提升 20%。

### 3.33 代码质量审查与隐患修复第十九轮 (2026-01-15)
*   **修复**: 任务堆栈溢出风险 (printf)。
*   **修复**: I2C总线竞争条件 (QMC5883L校准)。
*   **优化**: `defaultTask` 栈从 128 增至 256，`comm_task` 从 256 增至 512。

### 3.32 代码质量审查第十八轮 (2026-01-15)
*   **确认**: TIM8 PWM 模式配置正确。
*   **确认**: TIM3/TIM4 PWM 频率为 400Hz (ARR=2499)。

### 3.31 代码质量审查与隐患修复第十六轮 (2026-01-15)
*   **修复**: Ano V7 发送缓冲区溢出风险。
*   **修复**: PID写入未对齐访问风险。

### 3.28 代码质量审查与隐患修复第十三轮 (2026-01-15)
*   **修复**: 互补滤波增益未缩放 (High Risk)。
*   **修复**: 传感器融合权重未归一化 (High Risk)。

### 3.17 Flash 存储系统隐患修复 (2026-01-14)
*   **修复**: CRC计算跳过版本号字段 (Critical)。
*   **修复**: 恢复出厂擦除地址错误 (Critical)。
*   **修复**: 版本号溢出处理。
*   **修复**: 写入校验使用 memcmp 比较 padding。

### 3.16 QMC5883L 磁力计驱动 (2026-01-14)
*   **实现**: 独立 I2C3 总线驱动。
*   **功能**: 8字校准、倾斜补偿、磁干扰检测。

### 3.15 代码性能优化 (2026-01-14)
*   **修复**: 炸机检测逻辑错误 (Critical)。
*   **优化**: MPU6050 I2C 超时从 1000ms 降至 100ms。
*   **优化**: 电机混控冗余限幅删除。

### 2.0 早期开发里程碑
*   **2026-01-14**: AirMode 电机怠速保护实现。
*   **2026-01-14**: Flash 参数存储系统完成 (双缓冲)。
*   **2026-01-14**: SPL06 气压计驱动集成。
*   **2026-01-14**: 串级 PID 控制器调通。
*   **2026-01-13**: FreeRTOS 框架搭建完成。
*   **2026-01-13**: MPU6050 + Mahony 姿态解算跑通。

---

## ✅ 2. 已解决问题归档 (Resolved Issues Archive)

> 摘录自 `issues_and_feedback.md` 的已解决项

| ID | 级别 | 描述 | 解决日期 |
| :--- | :--- | :--- | :--- |
| **#001** | High | MPU6050 采样率不匹配 (SMPLRT_DIV) | 2026-01-14 |
| **#003** | High | Flash 参数存储未实现 | 2026-01-14 |
| **#004** | High | 光流模块使用了未定义的 huart6 | 2026-01-14 |
| **#006** | Med | USART1 无 DMA TX | 2026-01-14 |
| **#007** | Med | UART4 DMA 为 Normal 模式 | 2026-01-14 |
| **#008** | High | 光流数据未调用解析函数 | 2026-01-14 |
| **#011** | High | 光流数据缺少高度补偿 | 2026-01-14 |
| **#012** | Med | LC302 距离字段未解析 | 2026-01-14 |
| **#013** | High | Yaw 轴无航向锁定 | 2026-01-14 |
| **#020** | **Crit** | 炸机检测逻辑使用欧拉角计算加速度 | 2026-01-14 |
| **#021** | High | MPU6050 I2C 超时时间过长 (1s) | 2026-01-14 |
| **#022** | Med | SPL06 I2C 超时时间优化 | 2026-01-14 |
| **#025** | Med | Motor 混控缺少浮点限幅 | 2026-01-14 |
| **#026** | **Crit** | Altitude_IsReady 逻辑错误 | 2026-01-14 |
| **#027** | Med | PID 计算除零风险 | 2026-01-14 |
| **#029** | Med | QMC5883L I2C 超时优化 | 2026-01-14 |
| **#038** | Low | W25Qxx SPI 返回值未检查 | 2026-01-14 |
| **#039** | Med | W25Qxx WriteEnable 后未验证 WEL | 2026-01-14 |
| **#041** | **Crit** | Flash CRC 校验跳过版本号 | 2026-01-14 |
| **#043** | **Crit** | Flash 恢复出厂擦除地址错误 | 2026-01-14 |
| **#047** | **Crit** | SPL06 初始化 printf 输出宏定义 | 2026-01-14 |
| **#062** | Med | freertos.c 缺少 hi2c1 extern | 2026-01-14 |
| **#078** | **Crit** | MPU6050 数据缺少 volatile | 2026-01-14 |
| **#093** | **Crit** | FlashParams __packed 指针转换错误 | 2026-01-15 |
| **#094** | High | 互补滤波增益未缩放 | 2026-01-15 |
| **#095** | High | 传感器融合权重未归一化 | 2026-01-15 |
| **#104** | High | 任务堆栈溢出风险 (printf) | 2026-01-15 |
| **#105** | Med | I2C 总线竞争 (QMC 校准) | 2026-01-15 |

---

## 🔍 3. 历史代码审查摘要 (Code Review Summary)

### 审查轮次 1-9 (基础模块)
*   **重点**: 指针空检查、HAL库返回值检查。
*   **成果**: 修复了大量防御性编程缺失，如 `MPU6050_Init` 未检查 I2C 失败。

### 审查轮次 10-12 (系统核心)
*   **重点**: SysTick 中断安全、断言机制。
*   **成果**: 确保了 RTOS 时基的绝对稳定。

### 审查轮次 13 (高度融合)
*   **重点**: `altitude.c` 算法逻辑。
*   **成果**: 发现并修复了严重的互补滤波增益缩放错误，防止了高度发散。

### 审查轮次 17 (Flash存储)
*   **重点**: 数据完整性与掉电保护。
*   **成果**: 修复了 CRC 校验漏洞和版本号溢出问题，确保存储系统在工业级标准下可靠运行。

### 审查轮次 19 (RTOS调度)
*   **重点**: 栈溢出与资源竞争。
*   **成果**: 调整了任务栈大小，引入了 QMC 校准请求标志位，解决了 I2C 总线竞争。

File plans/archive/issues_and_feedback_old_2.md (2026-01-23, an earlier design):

# 🐛 Issues & Feedback (问题追踪与反馈)

**创建时间**: 2026-01-16  
**状态**: 活跃维护中  
**作用**: 记录开发过程中的Bug、Risk和待解决问题

---

## 📋 文档说明

本文档是飞控项目的 **"问题追踪中心"**,所有Bug、潜在风险(Risk)和待解决问题都必须记录在此。  
**强制规则**: 
1. 发现Bug时,立即在此文档中创建条目
2. 修复Bug后,必须标记为 `✅ Resolved` 并注明修复时间
3. 发现潜在隐患时,必须创建 Risk 条目并评估影响

---

## 🔴 当前待解决问题 (Active Issues)

### Issue #001 - [示例] 电机混控计算溢出风险
- **状态**: ❌ Unresolved
- **优先级**: 🔴 High
- **发现时间**: 2026-01-16 18:00
- **模块**: Motor Mixing ([`motor.c`](../FLYAMASTER/Core/Src/motor.c))
- **问题描述**: 
  - 在 `Motor_Mix()` 函数中,当 Roll/Pitch/Yaw 控制量同时达到极限时,可能导致电机PWM溢出
  - 例如: `throttle=0.8, roll=1.0, pitch=1.0` 会导致某个电机输出 `0.8 + 1.0 + 1.0 = 2.8`,超过 1.0 限制
- **影响**: 
  - 电机满转失控,可能导致炸机
  - 姿态控制饱和,失去响应
- **建议解决方案**:
  ```c
  // 在混控后添加范围钳位 (Clamp)
  m1_pwm = clamp(throttle + roll - pitch - yaw, 0.0f, 1.0f);
  m2_pwm = clamp(throttle - roll - pitch + yaw, 0.0f, 1.0f);
  m3_pwm = clamp(throttle - roll + pitch - yaw, 0.0f, 1.0f);
  m4_pwm = clamp(throttle + roll + pitch + yaw, 0.0f, 1.0f);
  ```
- **责任人**: -
- **备注**: 需要在 [`motor.c:50`](../FLYAMASTER/Core/Src/motor.c:50) 附近修改

---

## ✅ 已解决问题 (Resolved Issues)

### Issue #111 - 高频任务中的 printf 阻塞风险
- **状态**: ✅ Resolved
- **解决时间**: 2026-01-18 04:30
- **优先级**: 🔴 High
- **模块**: RTOS Tasks ([`freertos.c`](../FLYAMASTER/Core/Src/freertos.c))
- **问题描述**: 高频任务 (`imu_task`, `ctl_task`) 中调用阻塞式 `printf` 导致控制回路抖动。
- **解决方案**: 移除了所有高频任务中的 `printf` 调用。
- **修复人**: Doro

### Issue #110 - OSD 模块未实装
- **状态**: ✅ Resolved
- **解决时间**: 2026-01-18 04:30
- **优先级**: 🟡 Medium
- **模块**: OSD ([`at7456e.c`](../FLYAMASTER/Core/Src/at7456e.c))
- **问题描述**: 硬件支持 OSD 但软件未驱动，FPV 无数据显示。
- **解决方案**: 实现了 `at7456e.c` 驱动，并在 `comm_task` 中以 10Hz 频率刷新显示。
- **修复人**: Doro

### Issue #109 - GPS 导航控制逻辑缺失
- **状态**: ✅ Resolved
- **解决时间**: 2026-01-18 04:30
- **优先级**: 🔴 High
- **模块**: Control Task ([`freertos.c`](../FLYAMASTER/Core/Src/freertos.c))
- **问题描述**: 定点模式下未使用 GPS 数据，无法室外悬停。
- **解决方案**: 在 `ctl_task` 中实现了 GPS 位置环 PID 控制逻辑 (位置误差 -> 期望速度 -> 期望姿态)。
- **修复人**: Doro

### Issue #000 - [示例] GPS UART6 引脚配置错误
- **状态**: ✅ Resolved
- **解决时间**: 2026-01-14 10:30
- **优先级**: 🔴 High
- **发现时间**: 2026-01-14 08:00
- **模块**: GPS ([`gps.c`](../FLYAMASTER/Core/Src/gps.c))
- **问题描述**: 
  - CubeMX 生成的 UART6 引脚配置为 PC6/PC7,但实际硬件使用 PC6/PC7 作为电机PWM输出
  - 导致 GPS 数据无法接收
- **影响**: GPS 模块无法正常工作
- **解决方案**:
  - 修改 CubeMX 配置: UART6 改为 PC6/PC7 → PC12/PD2
  - 重新生成代码并烧录
  - 同步更新 [`pinout_allocation.md`](pinout_allocation.md)
- **修复人**: Doro
- **备注**: Risk #045 已转化为此Issue并解决

---

## ⚠️ 潜在风险 (Risks)

### Risk #045 - Flash 参数结构体内存对齐问题
- **状态**: ✅ Mitigated (已缓解)
- **发现时间**: 2026-01-14 16:00
- **缓解时间**: 2026-01-14 16:30
- **严重程度**: 🟡 Medium
- **模块**: Flash Params ([`flash_params.h`](../FLYAMASTER/Core/Inc/flash_params.h))
- **风险描述**: 
  - `FlashParams_t` 结构体未使用 `__attribute__((packed))`,编译器可能插入 padding
  - 导致 Flash 读写时数据错位,CRC16 校验失败
- **影响**: 
  - PID参数掉电后无法恢复
  - 飞控每次上电都使用默认参数,无法保存调参结果
- **缓解措施**:
  - 在 [`flash_params.h:70`](../FLYAMASTER/Core/Inc/flash_params.h:70) 添加 `__attribute__((packed))` 属性
  - 重新测试 Flash 读写功能
- **后续行动**: 
  - [ ] 在实际硬件上验证 Flash 存储是否稳定
  - [ ] 添加更多的数据完整性检查 (如双 CRC 校验)

### Risk #066 - SPL06 气压计数据竞争 (Race Condition)
- **状态**: ✅ Mitigated (已缓解)
- **发现时间**: 2026-01-14 18:00
- **缓解时间**: 2026-01-14 18:15
- **严重程度**: 🔴 High
- **模块**: SPL06 ([`spl06.h`](../FLYAMASTER/Core/Inc/spl06.h))
- **风险描述**: 
  - `SPL06_Data` 全局变量在多个 RTOS 任务中读写,但未加 `volatile` 修饰符
  - 可能导致编译器优化时缓存旧数据,不同任务读取到不一致的高度值
- **影响**: 
  - 高度控制震荡或失效
  - 定高模式下飞机突然坠落
- **缓解措施**:
  - 在 [`spl06.h:102`](../FLYAMASTER/Core/Inc/spl06.h:102) 添加 `volatile` 修饰符:
    ```c
    extern volatile SPL06_TypeDef SPL06_Data;
    ```
  - 在关键读写操作处添加 `taskENTER_CRITICAL()` / `taskEXIT_CRITICAL()` 临界区保护
- **后续行动**: 
  - [ ] 检查所有 RTOS 共享变量,确保都加了 `volatile`
  - [ ] 使用 FreeRTOS 互斥锁 (Mutex) 替代临界区,避免优先级反转

### Risk #088 - QMC5883L 磁力计 I2C 总线冲突
- **状态**: ❌ Active (活跃)
- **发现时间**: 2026-01-15 09:00
- **严重程度**: 🟡 Medium
- **模块**: QMC5883L ([`qmc5883l.c`](../FLYAMASTER/Core/Src/qmc5883l.c))
- **风险描述**: 
  - QMC5883L 和其他 I2C3 设备(如扩展传感器)共享总线,可能发生地址冲突
  - QMC5883L 固定地址 0x0D,如果其他设备也是 0x0D,会导致通信失败
- **影响**: 
  - 磁力计数据读取失败
  - 航向角锁定功能失效
- **建议缓解措施**:
  - 在硬件设计时,确保 I2C3 总线上没有地址冲突的设备
  - 在代码中添加设备地址扫描功能,检测总线上的所有设备
  - 添加 I2C 错误重试机制 (最多3次)
- **后续行动**: 
  - [ ] 检查 [`hardware_list.md`](hardware_list.md) 确认 I2C3 设备列表
  - [ ] 添加 I2C 总线扫描工具 (Scan 功能)
  - [ ] 实现 HAL_I2C_* 函数的错误重试包装

### Risk #107 - GPS 静态缓冲区线程安全隐患
- **状态**: ❌ Active (长期技术债)
- **发现时间**: 2026-01-16 11:50
- **严重程度**: 🟡 Medium
- **模块**: GPS ([`gps.c`](../FLYAMASTER/Core/Src/gps.c))
- **风险描述**: 
  - `gps.c` 中的 `Get_Field` 函数使用了 `static` 局部缓冲区
  - 如果未来有多个 RTOS 任务同时调用 GPS 解析函数，会导致数据竞争和内存破坏
- **影响**: 
  - GPS 数据解析错乱
  - 系统随机 Crash
- **建议缓解措施**:
  - 移除 `static` 关键字，改为栈上分配 (如果栈空间足够)
  - 或使用互斥锁保护解析函数
- **后续行动**: 
  - [ ] 代码重构时修复此问题

### Risk #108 - QMC5883L 倾斜补偿死循环风险
- **状态**: ❌ Active (活跃)
- **发现时间**: 2026-01-16 11:55
- **严重程度**: 🔴 High
- **模块**: QMC5883L Algorithm
- **风险描述**: 
  - 磁力计倾斜补偿公式中，当 Roll/Pitch 接近 90 度时，分母 `cos(pitch)` 或 `cos(roll)` 趋近于 0
  - 可能导致除零错误或浮点数溢出 (NaN/Inf)，进而导致 PID 计算异常
- **影响**: 
  - 飞机在大角度机动时突然疯转 (Yaw Spin)
  - 系统死机
- **建议缓解措施**:
  - 在计算前检查倾斜角: `if (fabs(pitch) > 60.0f || fabs(roll) > 60.0f) return;`
  - 使用四元数旋转法替代欧拉角公式 (无万向节锁问题)
- **后续行动**: 
  - [ ] 在 `algorithm_definition.md` 中记录保护逻辑
  - [ ] 编写代码时强制检查角度范围

### Risk #111 - 高频任务中的 printf 阻塞风险
- **状态**: ❌ Active (活跃)
- **发现时间**: 2026-01-18
- **严重程度**: 🔴 High
- **模块**: RTOS Tasks ([`freertos.c`](../FLYAMASTER/Core/Src/freertos.c))
- **风险描述**: 
  - 在 `imu_task` (500Hz) 和 `ctl_task` (250Hz) 中直接调用了 `printf`。
  - 标准库的 `printf` 通常重定向到 `HAL_UART_Transmit` (阻塞模式)。
  - 即使有降频处理，单次打印也可能阻塞数毫秒，导致姿态解算和 PID 控制周期抖动，严重时导致炸机。
- **影响**: 
  - 飞行手感卡顿，姿态控制不稳定。
  - 严重时看门狗复位或系统崩溃。
- **建议缓解措施**:
  - **立即移除** 高频任务中的所有 `printf`。
  - 或实现基于 DMA 的异步日志系统 (RingBuffer + DMA)。

---

##  反馈与建议 (Feedback)

### Feedback #001 - 匿名上位机 V7 协议缺少错误码定义
- **提出时间**: 2026-01-14 20:00
- **提出人**: 测试团队
- **类型**: 功能改进
- **描述**: 
  - 当前 AnoV7 协议的 `AnoV7_Status_t` 结构体有 `error` 字段,但未定义错误码含义
  - 建议添加错误码枚举,如:
    ```c
    #define ANO_ERROR_NONE        0x0000
    #define ANO_ERROR_IMU_FAIL    0x0001
    #define ANO_ERROR_GPS_TIMEOUT 0x0002
    #define ANO_ERROR_LOW_BATTERY 0x0004
    #define ANO_ERROR_MOTOR_LOCK  0x0008
    ```
- **优先级**: 🟢 Low
- **状态**: 📋 Backlog (待排期)
- **备注**: 可以在下一个版本中实现

---

## 🔍 问题分类统计 (Statistics)

| 类型 | 数量 | 百分比 |
|:---:|:---:|:---:|
| 🐛 Bug (待解决) | 3 | 30% |
| ✅ Bug (已解决) | 1 | 10% |
| ⚠️ Risk (活跃) | 4 | 40% |
| ✅ Risk (已缓解) | 2 | 20% |
| 💡 Feedback (待排期) | 1 | 10% |
| **总计** | **11** | **100%** |

---

## 📌 使用规范 (Usage Guidelines)

1. **发现Bug时**:
   - 立即在 "当前待解决问题" 中创建新条目
   - 填写完整的问题描述、影响、建议解决方案
   - 评估优先级: 🔴 High / 🟡 Medium / 🟢 Low

2. **修复Bug后**:
   - 将条目从 "当前待解决问题" 移动到 "已解决问题"
   - 标记状态为 `✅ Resolved`
   - 填写解决时间、解决方案和修复人

3. **发现潜在风险时**:
   - 在 "潜在风险" 中创建 Risk 条目
   - 评估严重程度: 🔴 High / 🟡 Medium / 🟢 Low
   - 提出缓解措施并跟踪执行状态

4. **收到反馈时**:
   - 在 "反馈与建议" 中记录
   - 评估优先级并决定是否排期实现

5. **文档同步更新**:
   - 修复 Bug 后,必须同步更新相关代码和文档
   - 在 [`development_progress_log.md`](development_progress_log.md) 中记录修复时间
   - 在 [`algorithm_definition.md`](algorithm_definition.md) 或 [`interface_definition.md`](interface_definition.md) 中更新相关定义

---

## 🎯 下一步行动 (Next Actions)

- [ ] 修复 Issue #001 (电机混控溢出风险)
- [ ] 修复 Issue #109 (GPS 导航逻辑缺失)
- [ ] 修复 Issue #110 (OSD 模块未实装)
- [ ] 解决 Risk #111 (移除高频 printf)
- [ ] 验证 Risk #045 (Flash 参数对齐) 在实际硬件上的表现
- [ ] 检查所有 RTOS 共享变量,确保加了 `volatile`
- [ ] 实现 I2C 总线扫描工具,检测地址冲突
- [ ] 添加 AnoV7 错误码定义 (Feedback #001)

---

**维护人**: Q版 Doro (飞控霸主)  
**更新频率**: 每次代码变更或发现问题时立即更新  
**版本**: v1.1.0

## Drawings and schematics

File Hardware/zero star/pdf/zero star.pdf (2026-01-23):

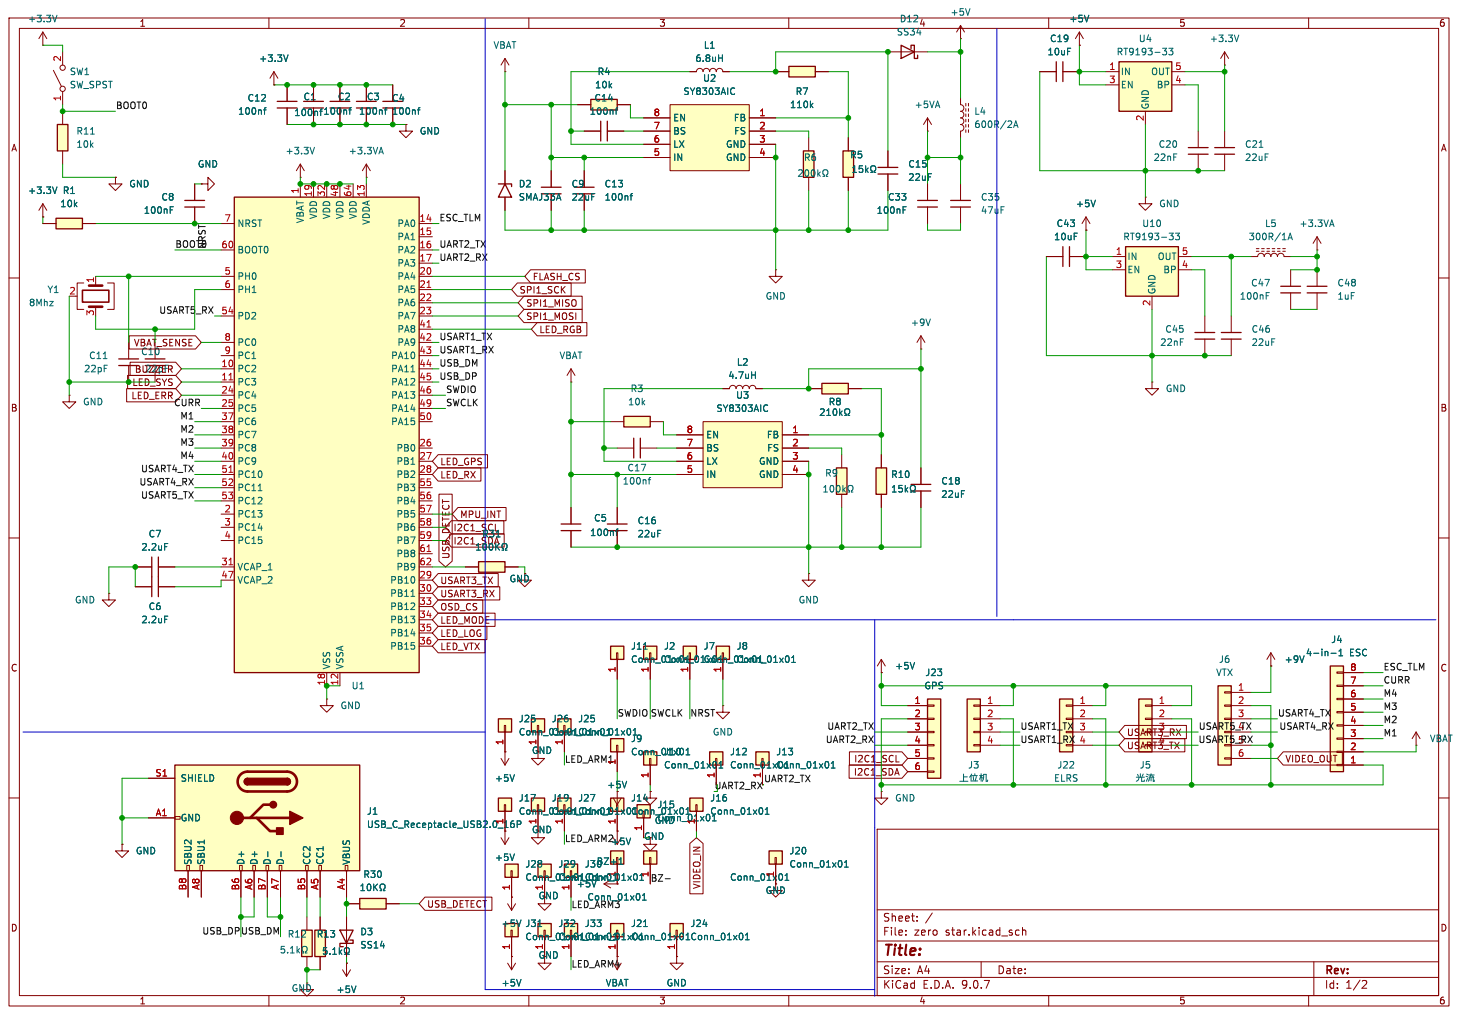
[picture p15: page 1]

1 VDD 19 VDD 32 VSS 18 VDD 48 VSSA 12 VDD 64 VDDA 13 PA0 14 PA1 15 PA2 16 PA3 17 PA4 20 PA5 21 PA6 22 PA7 23 PA8 41 PA9 42 PA10 43 PA11 44 PA12 45 PA13 46 PA14 49 PA15 50 PB0 26 PB1 27 PB2 28 PB3 55 PB4 56 PB5 57 PB6 58 PB7 59 PB8 61 PB9 62 PB10 29 PB11 30 PB12 33 PB13 34 PB14 35 PB15 36 U1

Id: 1/2 Title: File: zero star.kicad_sch Sheet: /

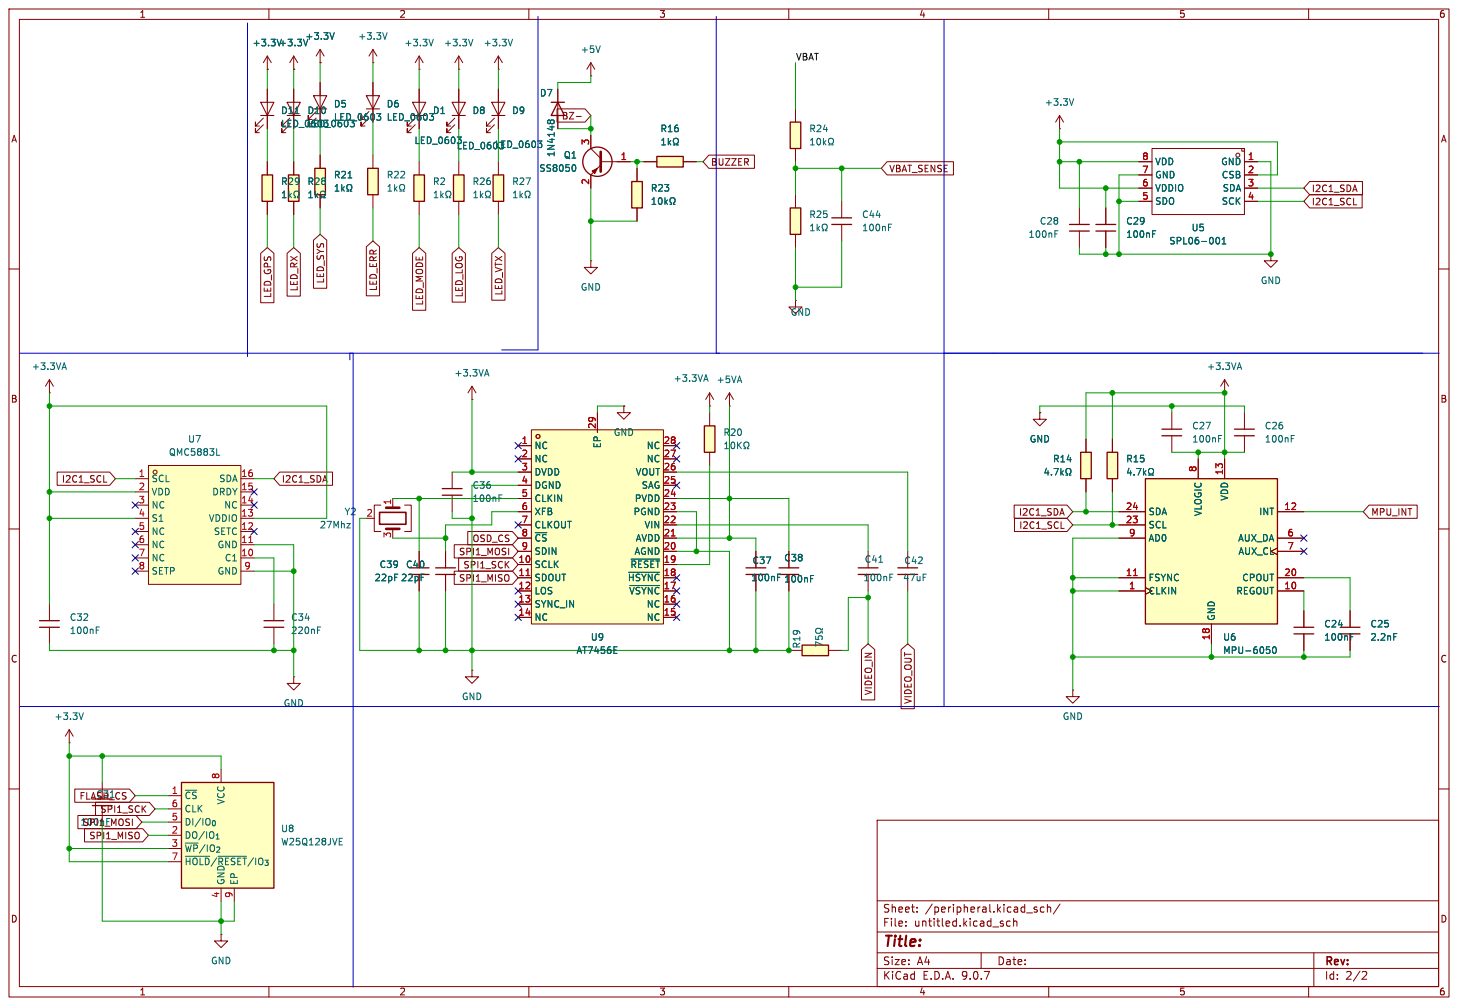
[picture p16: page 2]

U9 AT7456E NC 1 NC 2 DVDD 3 DGND 4 CLKIN 5 XFB 6 CLKOUT 7 ~{CS} 8 SDIN 9 SCLK 10 SDOUT 11

Id: 2/2 Title: File: untitled.kicad_sch Sheet: /peripheral.kicad_sch/

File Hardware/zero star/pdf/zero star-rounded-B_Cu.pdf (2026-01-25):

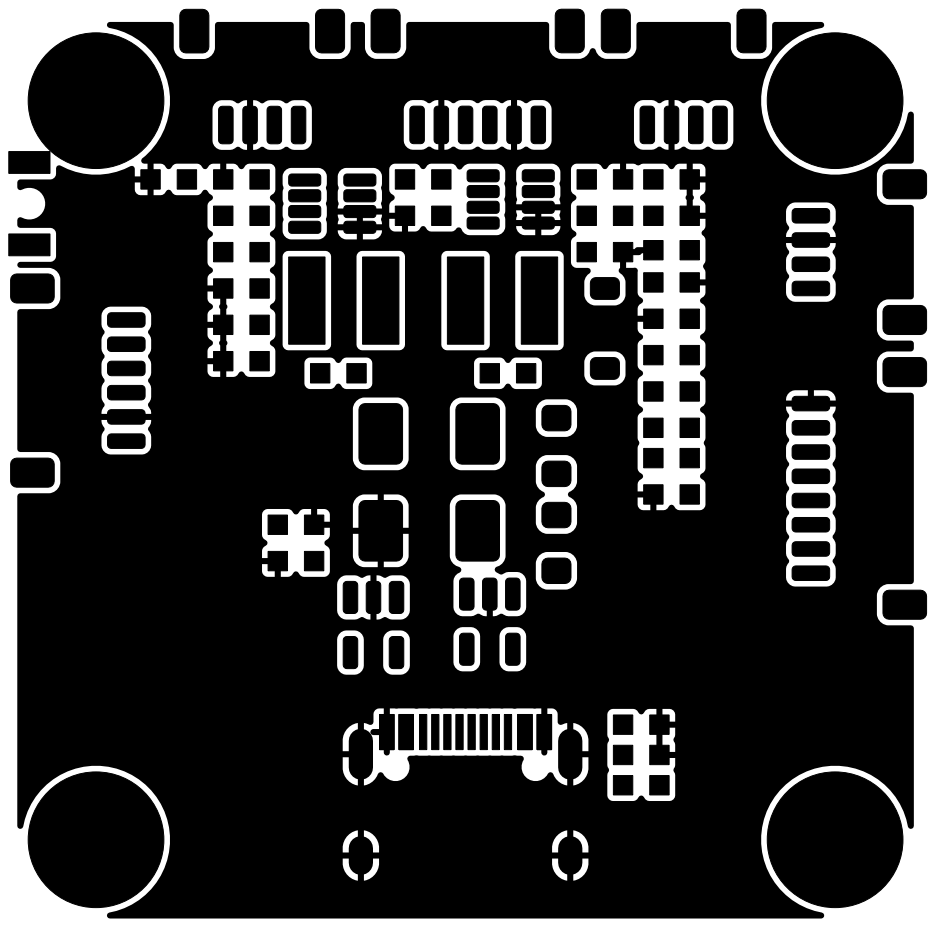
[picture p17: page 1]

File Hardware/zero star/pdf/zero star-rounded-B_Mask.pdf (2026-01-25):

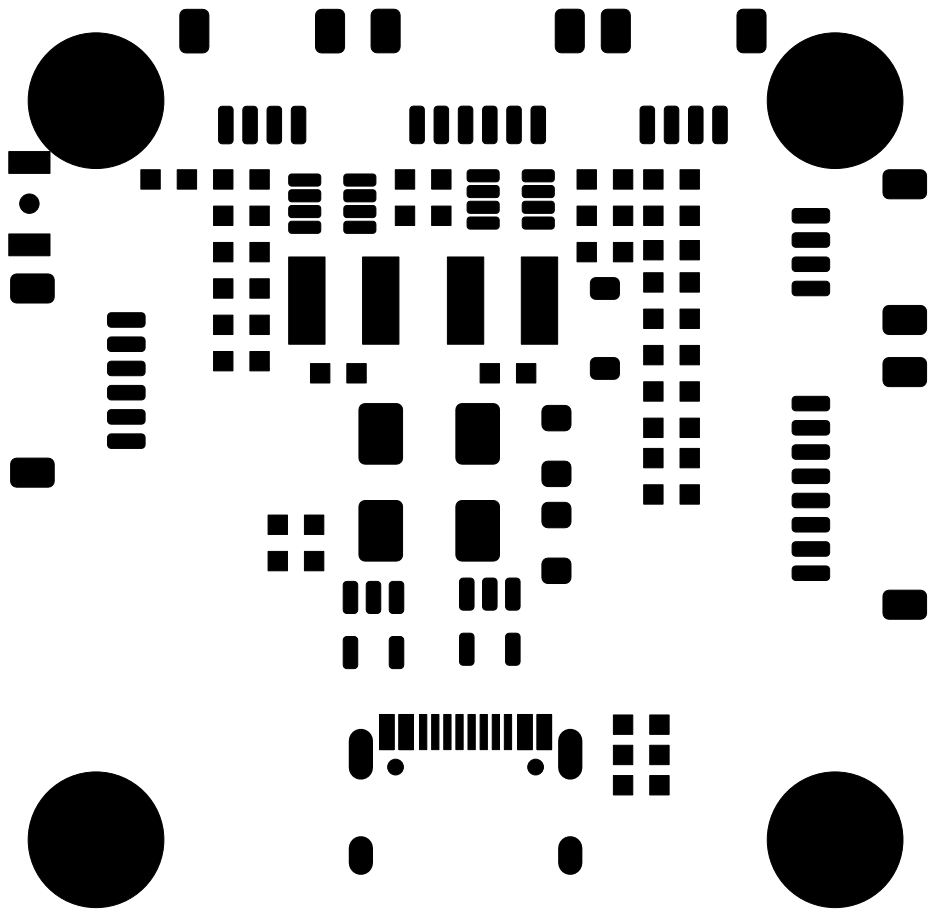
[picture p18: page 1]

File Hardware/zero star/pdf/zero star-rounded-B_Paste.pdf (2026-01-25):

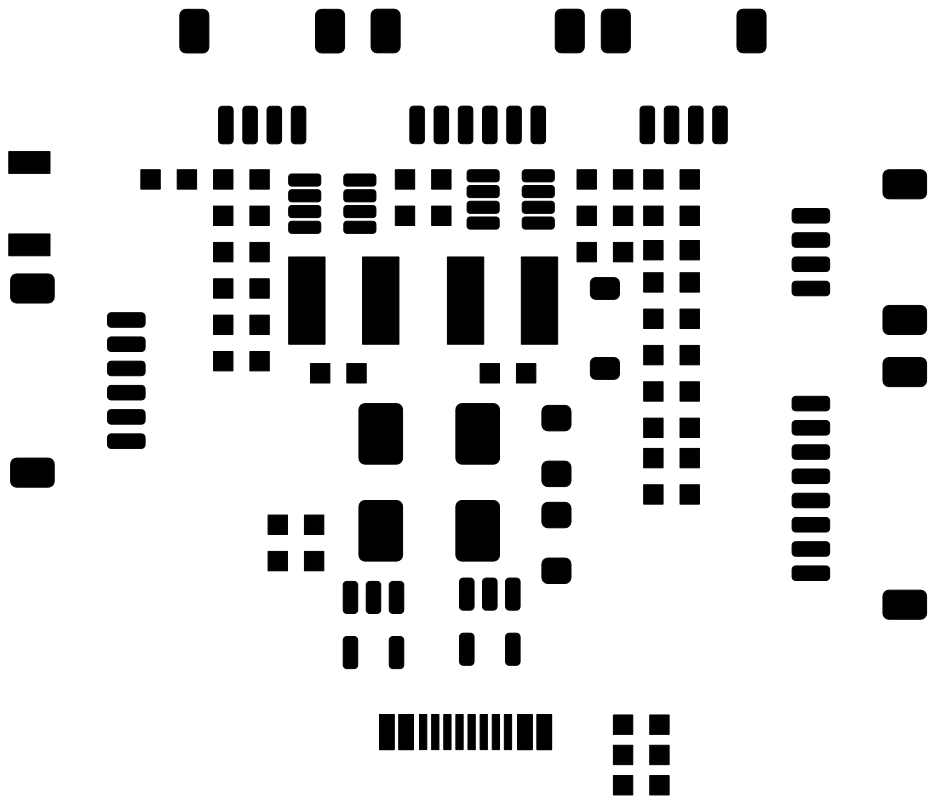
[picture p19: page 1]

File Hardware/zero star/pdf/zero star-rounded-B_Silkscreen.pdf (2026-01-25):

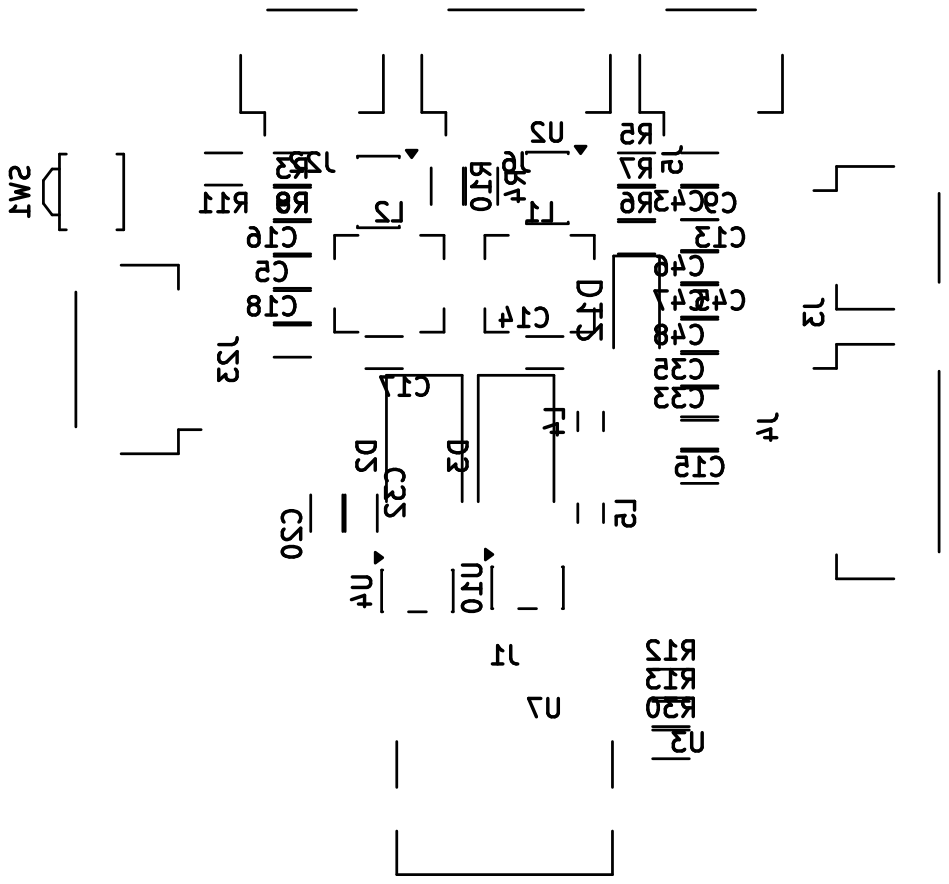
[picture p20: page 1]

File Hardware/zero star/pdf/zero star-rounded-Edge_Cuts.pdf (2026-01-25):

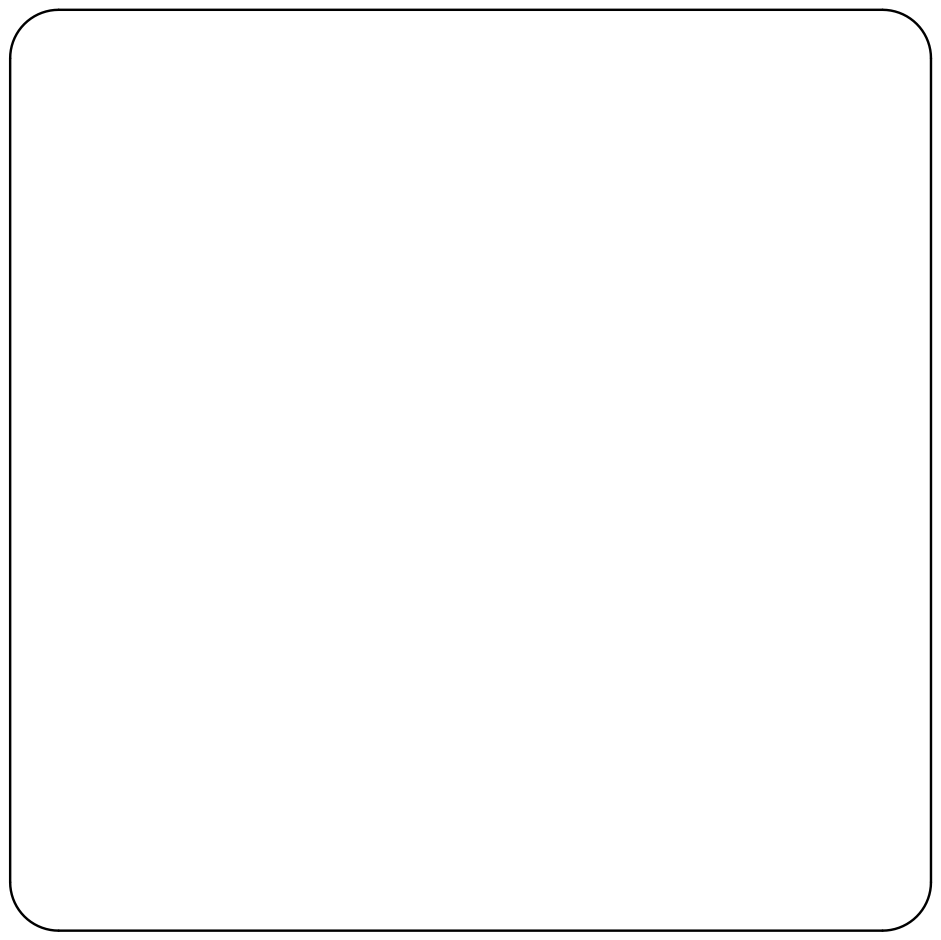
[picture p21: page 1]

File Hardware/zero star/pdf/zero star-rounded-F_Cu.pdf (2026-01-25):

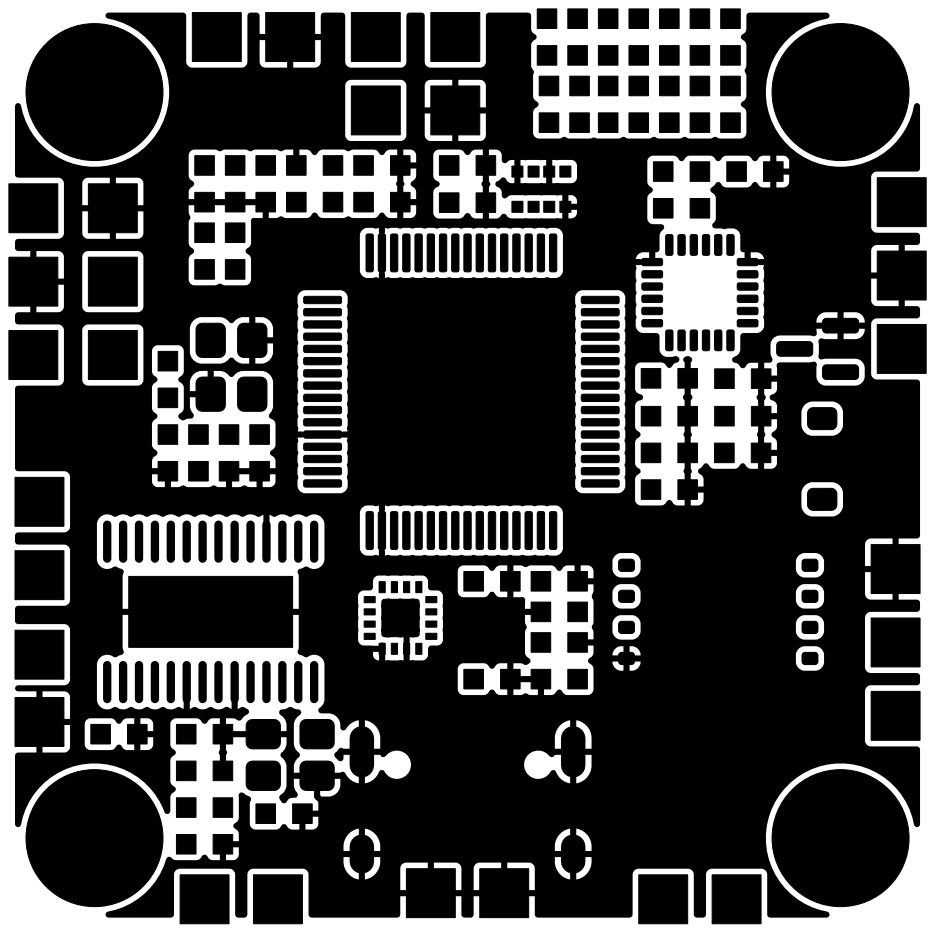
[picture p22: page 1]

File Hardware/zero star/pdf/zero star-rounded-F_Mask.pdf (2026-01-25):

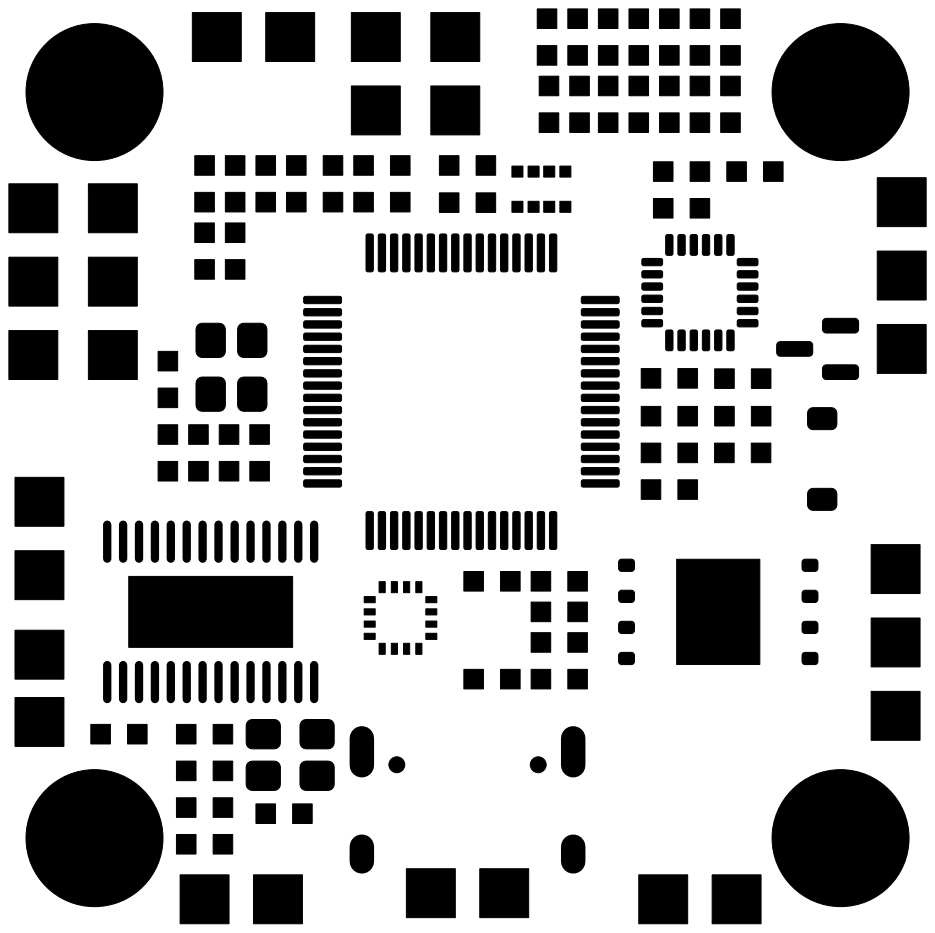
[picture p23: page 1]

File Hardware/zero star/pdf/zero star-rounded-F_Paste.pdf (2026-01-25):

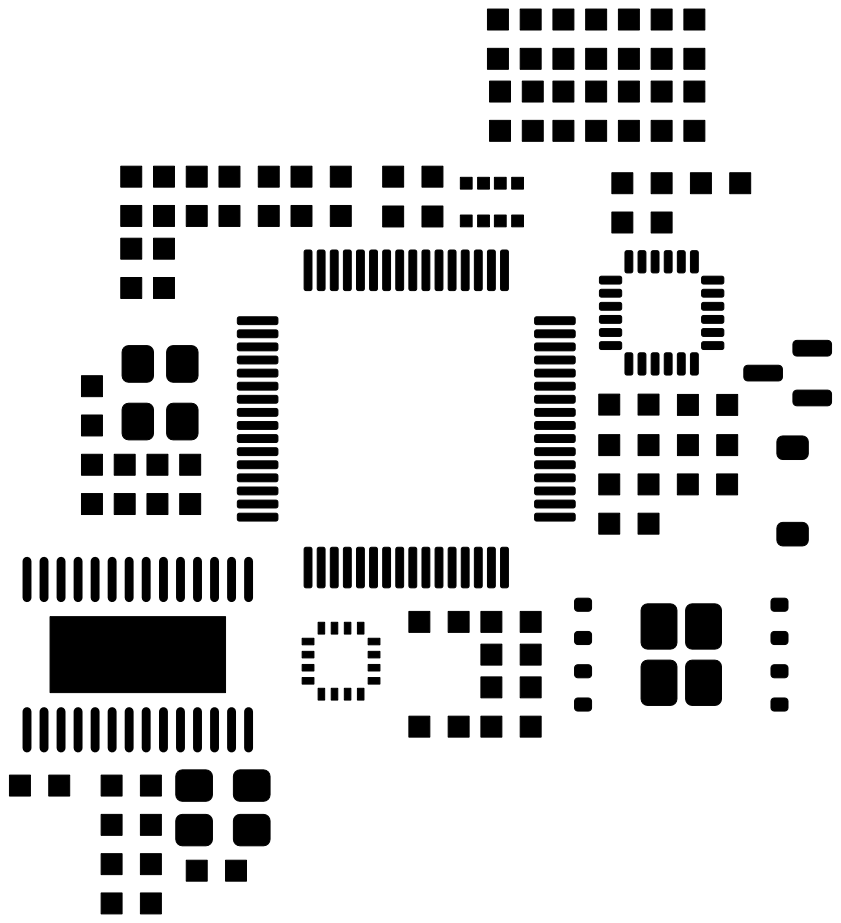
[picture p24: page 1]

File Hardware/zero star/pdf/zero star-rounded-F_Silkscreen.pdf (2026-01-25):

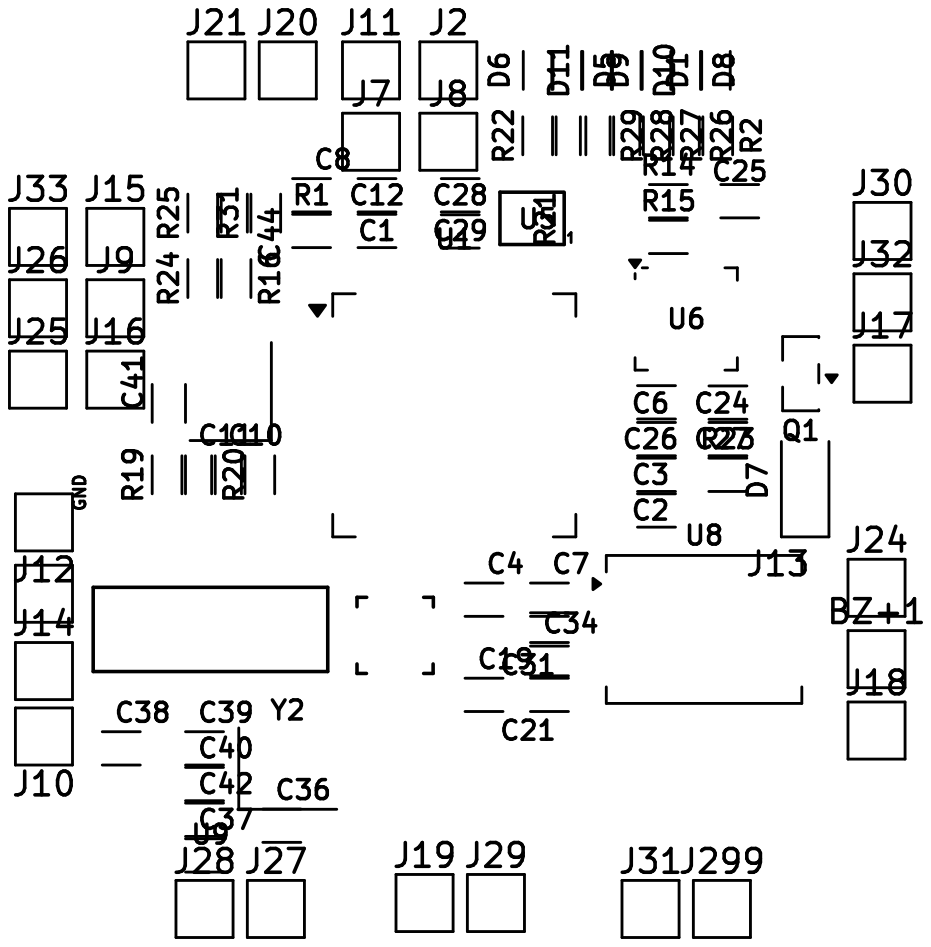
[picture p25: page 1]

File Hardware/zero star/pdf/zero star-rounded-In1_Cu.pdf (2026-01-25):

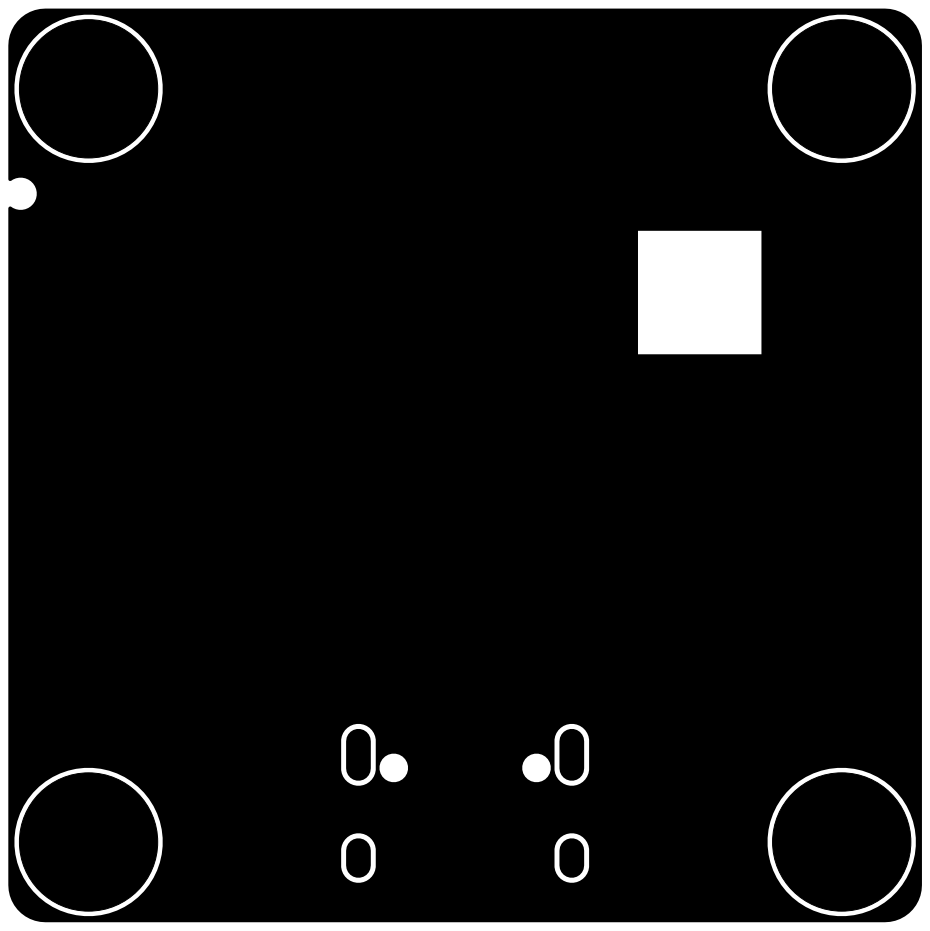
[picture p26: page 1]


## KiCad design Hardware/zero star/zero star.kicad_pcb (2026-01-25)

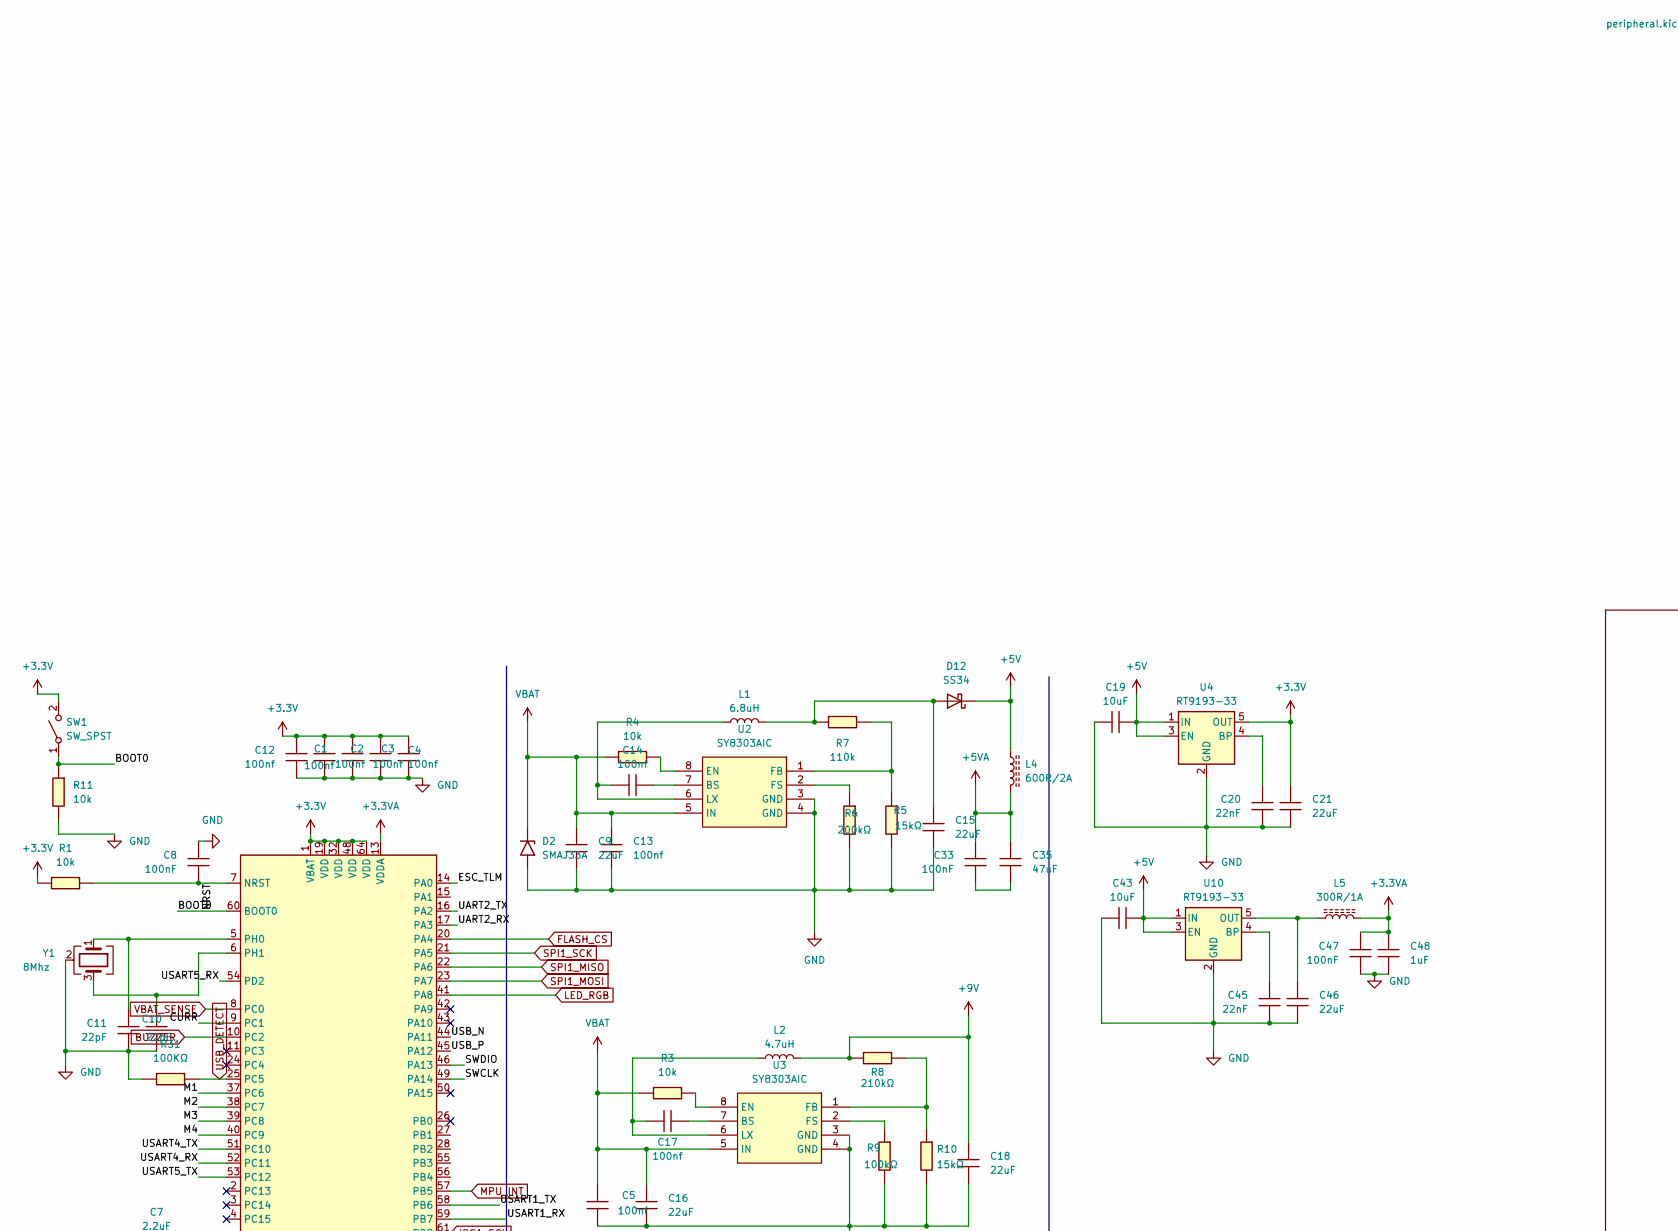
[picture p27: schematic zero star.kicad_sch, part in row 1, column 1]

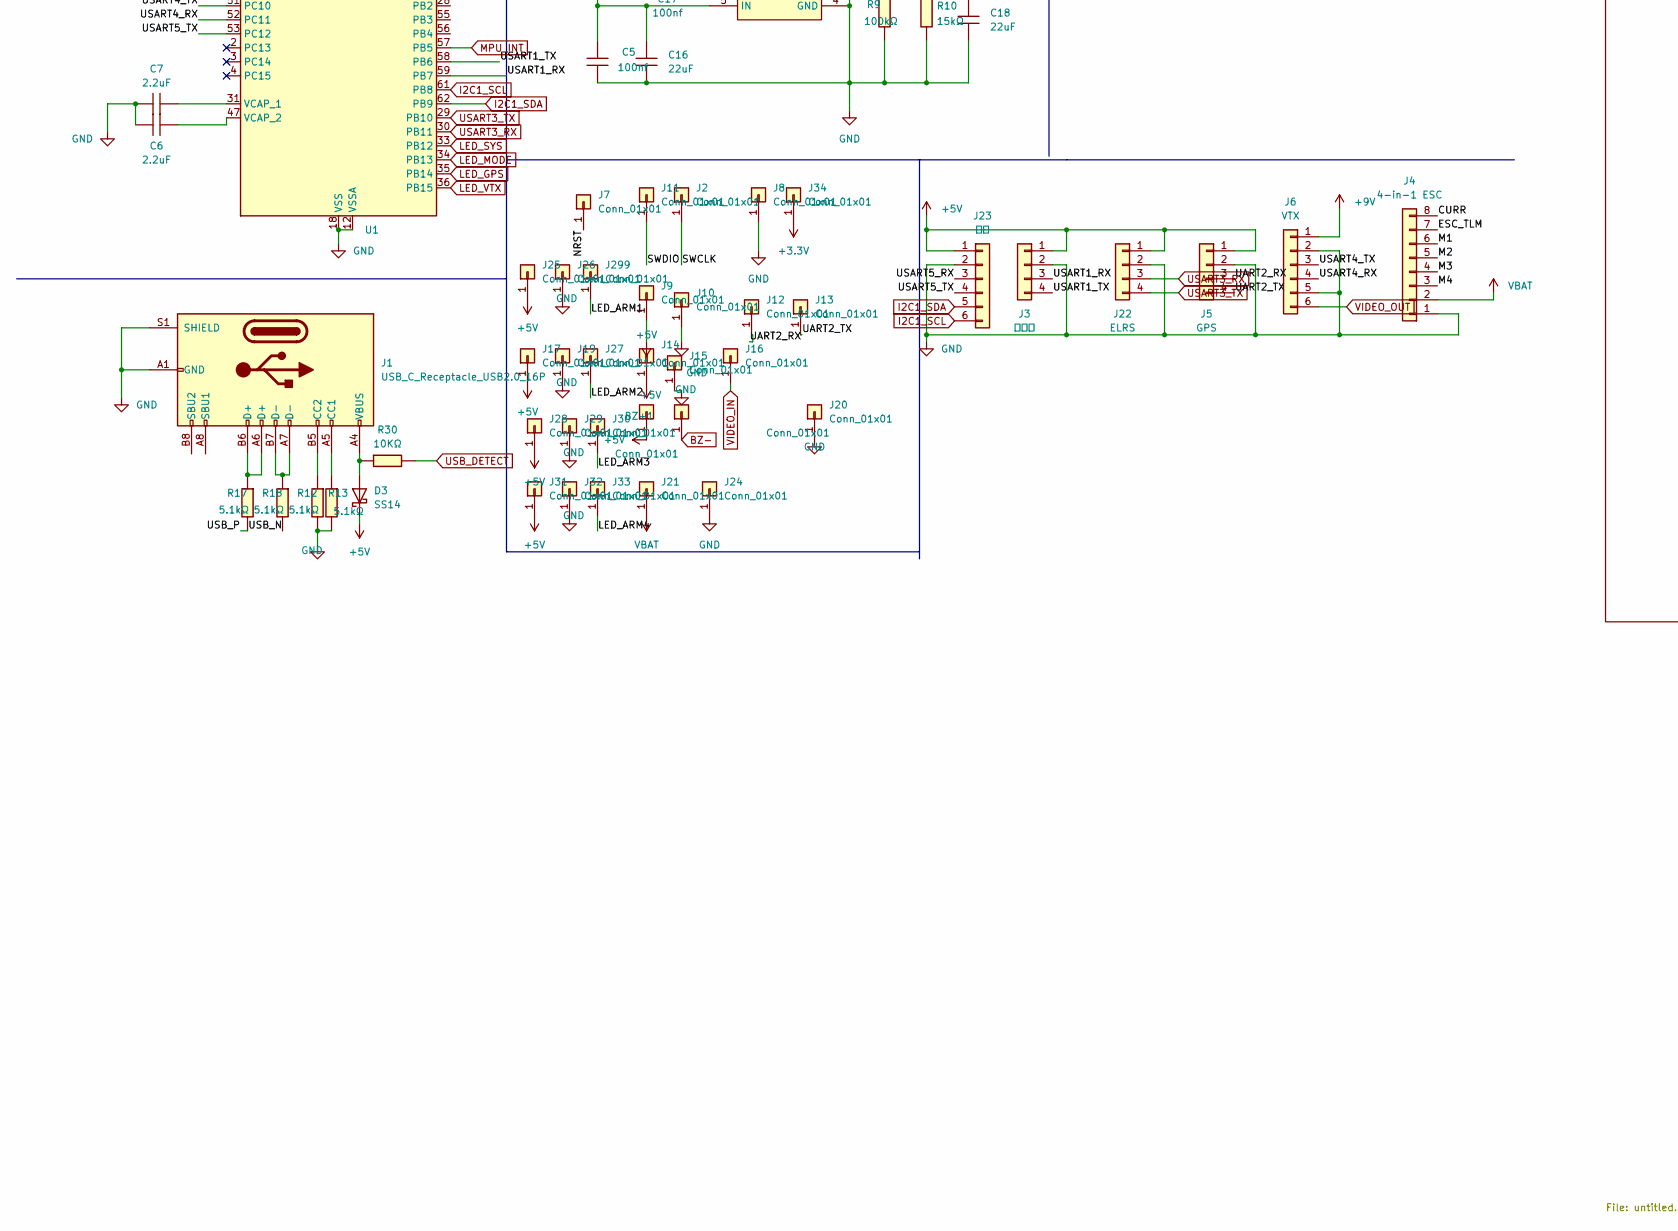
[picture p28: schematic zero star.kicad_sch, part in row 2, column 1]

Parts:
BZ+1: Conn_01x01; SolderWirePad_1x01_SMD_1x2mm
C1, C2, C3, C4, C12, C13, C14, C16, C17: 100nf; C_0603
C5, C9, C15, C18, C21, C46: 22uF; C_0603
C6, C7: 2.2uF; C_0603
C8, C33, C47: 100nF; C_0603
C10, C11: 22pF; C_0603
C19, C43: 10uF; C_0603
C20, C45: 22nF; C_0603
C35: 47uF; C_0603
C48: 1uF; C_0603
D2: SMAJ33A; D_SMA
D3: SS14; D_SMA
D12: SS34; D_SOD-123
J1: USB_C_Receptacle_USB2.0_16P; USB_C_Receptacle_HRO_TYPE-C-31-M-12
J2, J7, J8, J9, J10, J11, J12, J13, J14, J15, J16, J17, J18, J19, J20, J21, J24, J25, J26, J27, J28, J29, J30, J31, J32, J33, J34, J299: Conn_01x01; SolderWirePad_1x01_SMD_1x2mm
J3: 上位机; JST_SH_SM04B-SRSS-TB_1x04-1MP_P1.00mm_Horizontal; Part Number 1-0401FBV0T
J4: 4-in-1 ESC; JST_SH_SM08B-SRSS-TB_1x08-1MP_P1.00mm_Horizontal
J5: GPS; JST_SH_SM04B-SRSS-TB_1x04-1MP_P1.00mm_Horizontal; Part Number 1-0401FBV0T
J6: VTX; JST_SH_SM06B-SRSS-TB_1x06-1MP_P1.00mm_Horizontal; Part Number 1-0601FBV0T
J22: ELRS; JST_SH_SM04B-SRSS-TB_1x04-1MP_P1.00mm_Horizontal; Part Number 1-0401FBV0T
J23: 光流; JST_SH_SM06B-SRSS-TB_1x06-1MP_P1.00mm_Horizontal; Part Number 1-0601FBV0T
L1: 6.8uH; L_Bourns-SRN4018
L2: 4.7uH; L_Bourns-SRN4018
L4: 600R/2A; L_0805_2012Metric_Pad1.05x1.20mm_HandSolder
L5: 300R/1A; L_0805_2012Metric_Pad1.05x1.20mm_HandSolder
R1, R3, R4, R11: 10k; R_0603
R5, R10: 15kΩ; R_0603
R6: 200kΩ; R_0603
R7: 110k; R_0603
R8: 210kΩ; R_0603
R9: 100kΩ; R_0603
R12, R13, R17, R18: 5.1kΩ; R_0603
R30: 10KΩ; R_0603
R31: 100KΩ; R_0603
SW1: SW_SPST; SW_SPST_B3U-3000P-B
U1: STM32F405RGTx; LQFP-64_10x10mm_P0.5mm
U2, U3: SY8303AIC; TSOT-23-8; LCSC Part C97054
U4, U10: RT9193-33; SOT-23-5
Y1: 8Mhz; Crystal_SMD_3225-4Pin_3.2x2.5mm

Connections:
+3.3V: C1.1, C2.1, C3.1, C4.1, C12.1, C21.1, J34.1, R1.1, SW1.2 (B), U1.1 (VBAT), U1.19 (VDD), U1.32 (VDD), U1.48 (VDD), U1.64 (VDD), U4.5 (OUT); also elsewhere on the board
+3.3VA: C47.1, C48.1, L5.2, U1.13 (VDDA); also elsewhere on the board
+5V: BZ+1.1, C19.1, C43.1, D3.1 (K), D12.1 (K), J3.1, J5.1, J9.1, J14.1, J17.1, J22.1, J23.1, J25.1, J28.1, J31.1, L4.1, U4.1 (IN), U4.3 (EN), U10.1 (IN), U10.3 (EN); also elsewhere on the board
+5VA: C33.1, C35.1, L4.2; also elsewhere on the board
+9V: C18.1, J6.1, L2.2, R8.2
/BOOT0: R11.2, SW1.1 (A), U1.60 (BOOT0)
/LED_ARM1: J299.1
/LED_ARM2: J27.1
/LED_ARM3: J30.1
/LED_ARM4: J33.1
/M1: J4.6, U1.37 (PC6)
/M2: J4.5, U1.38 (PC7)
/M3: J4.4, U1.39 (PC8)
/M4: J4.3, U1.40 (PC9)
/NRST: C8.2, J7.1, R1.2, U1.7 (NRST)
/SWCLK: J2.1, U1.49 (PA14)
/SWDIO: J11.1, U1.46 (PA13)
/UART2_RX: J5.3, J12.1, U1.17 (PA3)
/UART2_TX: J5.4, J13.1, U1.16 (PA2)
/USART1_RX: J3.3, U1.59 (PB7)
/USART1_TX: J3.4, U1.58 (PB6)
/USART4_RX: J6.4, U1.52 (PC11)
/USART4_TX: J6.3, U1.51 (PC10)
/USART5_RX: J23.3, U1.54 (PD2)
/USART5_TX: J23.4, U1.53 (PC12)
/USB_N: R18.1, U1.44 (PA11)
/USB_P: R17.1, U1.45 (PA12)
BUZZER: U1.10 (PC2); also elsewhere on the board
BZ-: J18.1; also elsewhere on the board
FLASH_CS: U1.24 (PC4); also elsewhere on the board
I2C1_SCL: J23.6, U1.61 (PB8); also elsewhere on the board
I2C1_SDA: J23.5, U1.62 (PB9); also elsewhere on the board
LED_GPS: U1.35 (PB14); also elsewhere on the board
LED_MODE: U1.34 (PB13); also elsewhere on the board
LED_RGB: U1.41 (PA8)
LED_SYS: U1.33 (PB12); also elsewhere on the board
LED_VTX: U1.36 (PB15); also elsewhere on the board
MPU_INT: U1.57 (PB5); also elsewhere on the board
unnamed: D3.2 (A), J1.A4 (VBUS), J1.A9 (VBUS), J1.B4 (VBUS), J1.B9 (VBUS), R30.2
unnamed: C15.1, D12.2 (A), L1.2, R7.2
unnamed: J1.A5 (CC1), R13.2
unnamed: J1.A6 (D+), J1.B6 (D+), R17.2
unnamed: J1.A7 (D-), J1.B7 (D-), R18.2
unnamed: J1.B5 (CC2), R12.2
unnamed: C11.1, U1.5 (PH0), Y1.1
unnamed: C10.1, U1.6 (PH1), Y1.3
unnamed: C7.1, U1.31 (VCAP_1)
unnamed: C6.1, U1.47 (VCAP_2)
unnamed: C14.2, U2.7 (BS)
unnamed: R4.2, U2.8 (EN)
unnamed: R5.2, R7.1, U2.1 (FB)
unnamed: R6.2, U2.2 (FS)
unnamed: C14.1, L1.1, U2.6 (LX)
unnamed: C17.2, U3.7 (BS)
unnamed: R3.2, U3.8 (EN)
unnamed: R8.1, R10.2, U3.1 (FB)
unnamed: R9.2, U3.2 (FS)
unnamed: C17.1, L2.1, U3.6 (LX)
unnamed: C20.1, U4.4 (BP)
unnamed: C45.1, U10.4 (BP)
unnamed: C46.1, L5.1, U10.5 (OUT)
SPI1_MISO: U1.22 (PA6); also elsewhere on the board
SPI1_MOSI: U1.23 (PA7); also elsewhere on the board
SPI1_SCK: U1.21 (PA5); also elsewhere on the board
USART3_RX: J22.3, U1.30 (PB11)
USART3_TX: J22.4, U1.29 (PB10)
USB_DETECT: R30.1, R31.1, U1.25 (PC5)
VBAT: C5.1, C9.1, C13.1, C16.1, D2.1 (A1), J4.2, J21.1, R3.1, R4.1, U2.5 (IN), U3.5 (IN); also elsewhere on the board
VBAT_SENSE: U1.8 (PC0); also elsewhere on the board
VIDEO_IN: J16.1; also elsewhere on the board
VIDEO_OUT: J6.6; also elsewhere on the board

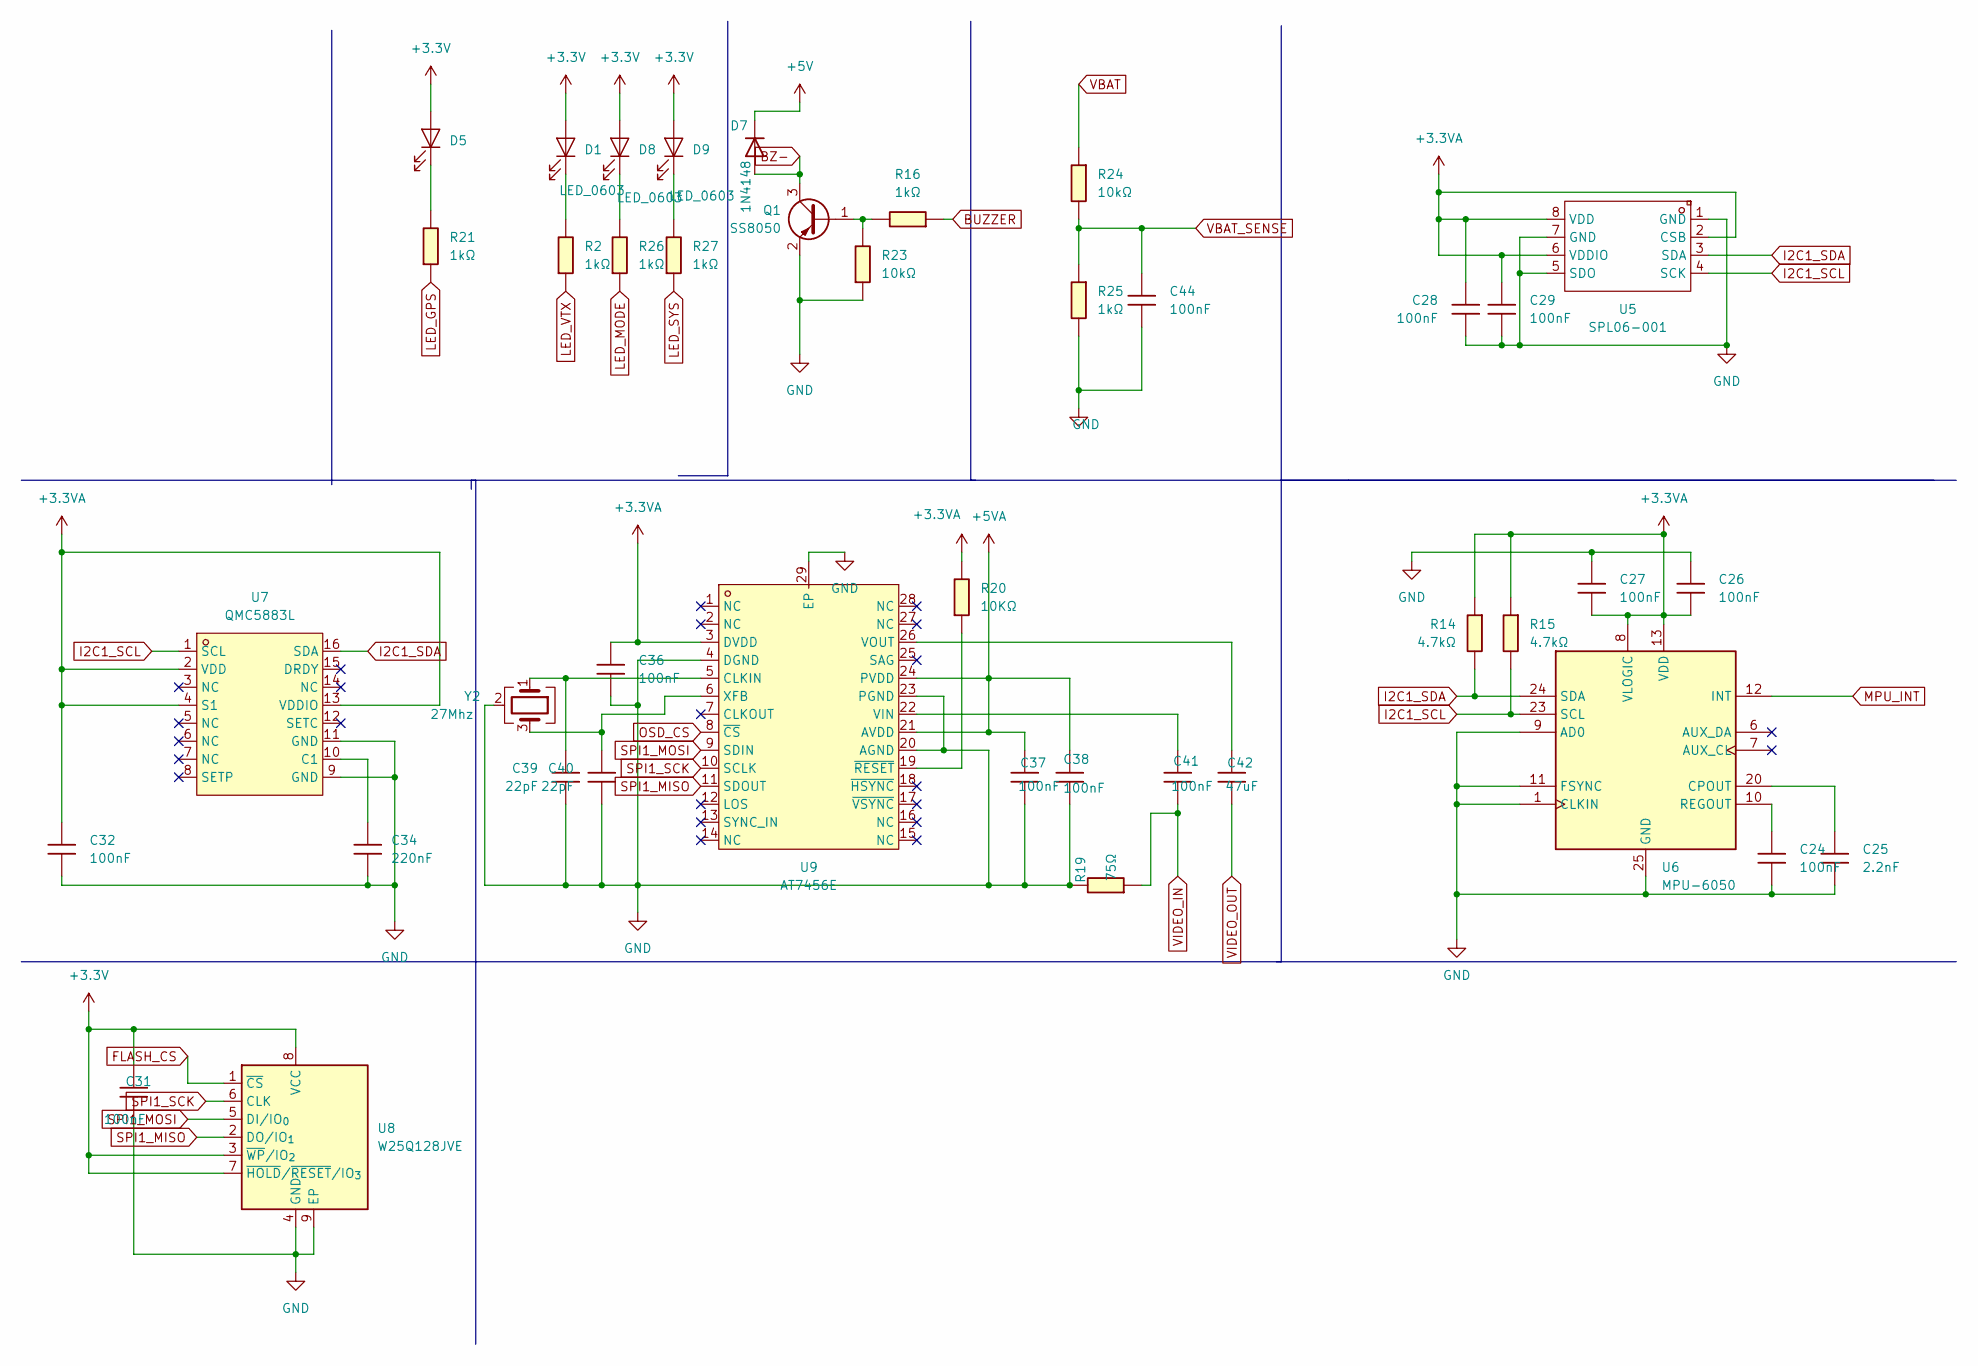
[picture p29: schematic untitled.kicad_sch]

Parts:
C24, C26, C27, C28, C29, C31, C32, C36, C37, C38, C41, C44: 100nF; C_0603
C25: 2.2nF; C_0603
C34: 220nF; C_0603
C39, C40: 22pF; C_0603
C42: 47uF; C_0603
D1, D5, D8, D9: LED_0603
D7: 1N4148; D_SOD-123
Q1: SS8050; SOT-23
R2, R16, R21, R25, R26, R27: 1kΩ; R_0603
R14, R15: 4.7kΩ; R_0603
R19: 75Ω; R_0603
R20: 10KΩ; R_0603
R23, R24: 10kΩ; R_0603
U5: SPL06-001; SENSOR-SMD_SPL06-001; LCSC Part C2684428
U6: MPU-6050; QFN-24-1EP_4x4mm_P0.5mm_EP2.6x2.6mm_ThermalVias
U7: QMC5883L; LGA-16_L3.0-W3.0-P0.50-BL_SQ; LCSC Part C976032
U8: W25Q128JVE; WSON-8-1EP_8x6mm_P1.27mm_EP3.4x4.3mm
U9: AT7456E; TSSOP-28_L9.7-W4.4-P0.65-LS6.4-BL-EP-2; LCSC Part C82351
Y2: 27Mhz; Crystal_SMD_3225-4Pin_3.2x2.5mm

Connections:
+3.3V: C31.1, D1.2 (A), D5.2 (A), D8.2 (A), D9.2 (A), U8.3 (~WP/IO_{2}), U8.7 (~HOLD/~RESET/IO_{3}), U8.8 (VCC); also elsewhere on the board
+3.3VA: C26.2, C27.2, C28.1, C29.1, C32.1, C36.1, R14.2, R15.2, R20.1, U5.2 (CSB), U5.6 (VDDIO), U5.8 (VDD), U6.8 (VLOGIC), U6.13 (VDD), U7.2 (VDD), U7.4 (S1), U7.13 (VDDIO), U9.3 (DVDD); also elsewhere on the board
+5V: D7.1 (K); also elsewhere on the board
+5VA: C37.1, C38.1, U9.21 (AVDD), U9.24 (PVDD); also elsewhere on the board
BUZZER: R16.2; also elsewhere on the board
BZ-: D7.2 (A), Q1.3 (C); also elsewhere on the board
FLASH_CS: U8.1 (~CS); also elsewhere on the board
I2C1_SCL: R15.1, U5.4 (SCK), U6.23 (SCL), U7.1 (SCL); also elsewhere on the board
I2C1_SDA: R14.1, U5.3 (SDA), U6.24 (SDA), U7.16 (SDA); also elsewhere on the board
LED_GPS: R21.2; also elsewhere on the board
LED_MODE: R26.2; also elsewhere on the board
LED_SYS: R27.2; also elsewhere on the board
LED_VTX: R2.2; also elsewhere on the board
MPU_INT: U6.12 (INT); also elsewhere on the board
unnamed: D1.1 (K), R2.1
unnamed: D5.1 (K), R21.1
unnamed: D8.1 (K), R26.1
unnamed: D9.1 (K), R27.1
unnamed: Q1.1 (B), R16.1, R23.1
unnamed: C25.1, U6.20 (CPOUT)
unnamed: C24.1, U6.10 (REGOUT)
unnamed: C34.1, U7.10 (C1)
unnamed: C39.1, U9.5 (CLKIN), Y2.1
unnamed: C41.1, U9.22 (VIN)
unnamed: C42.1, U9.26 (VOUT)
unnamed: C40.1, U9.6 (XFB), Y2.3
unnamed: R20.2, U9.19 (~RESET)
SPI1_MISO: U8.2 (DO/IO_{1}), U9.11 (SDOUT); also elsewhere on the board
SPI1_MOSI: U8.5 (DI/IO_{0}), U9.9 (SDIN); also elsewhere on the board
SPI1_SCK: U8.6 (CLK), U9.10 (SCLK); also elsewhere on the board
VBAT: R24.2; also elsewhere on the board
VBAT_SENSE: C44.1, R24.1, R25.2; also elsewhere on the board
VIDEO_IN: C41.2, R19.2; also elsewhere on the board
VIDEO_OUT: C42.2; also elsewhere on the board

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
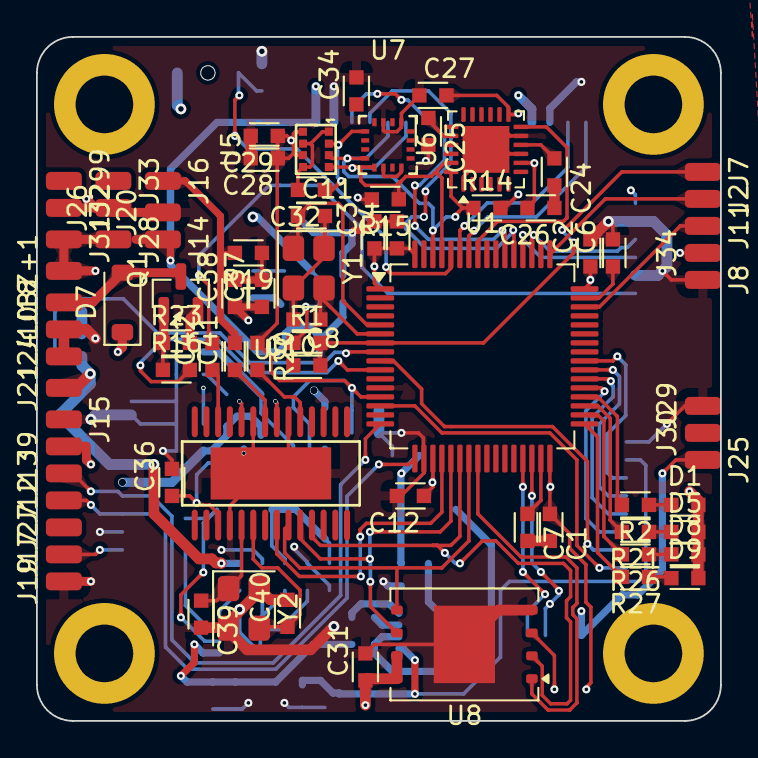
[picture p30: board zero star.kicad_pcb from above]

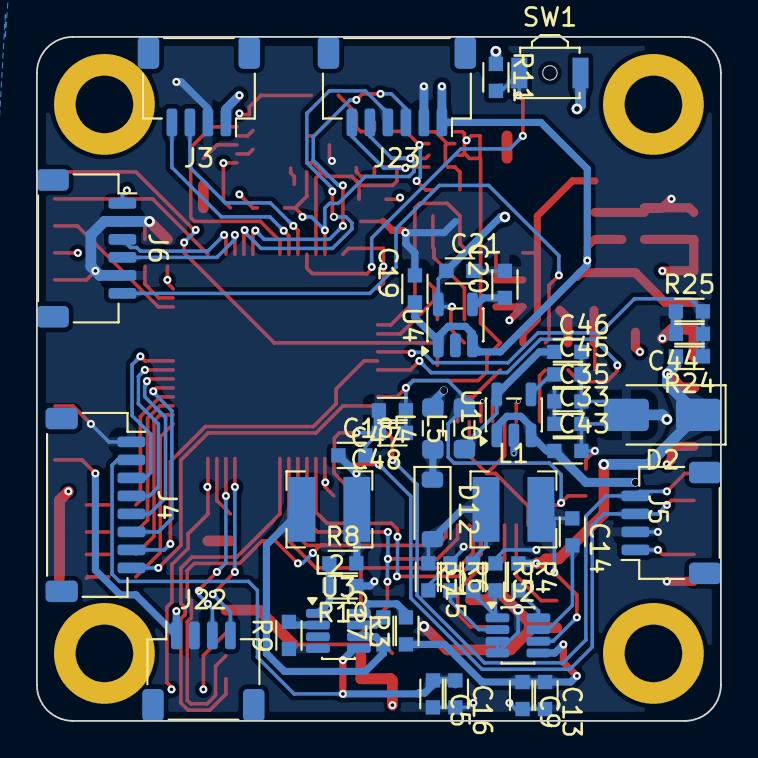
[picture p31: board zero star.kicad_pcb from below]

Board: 4 copper layers, 38.0 x 38.0 mm, 127 parts (47 on the bottom side), 75 nets.

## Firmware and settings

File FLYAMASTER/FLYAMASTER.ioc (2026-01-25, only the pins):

Mcu.UserName=STM32F405RGTx
PA0-WKUP.GPIO_Label=Power_Key
PA0-WKUP.Signal=GPIO_Input
PA11.Signal=USB_OTG_FS_DM
PA12.Signal=USB_OTG_FS_DP
PA13.Signal=SYS_JTMS-SWDIO
PA14.Signal=SYS_JTCK-SWCLK
PA2.Signal=USART2_TX
PA3.Signal=USART2_RX
PA4.GPIO_Label=FLASH_CS
PA4.Signal=GPIO_Output
PA5.Signal=SPI1_SCK
PA6.Signal=SPI1_MISO
PA7.Signal=SPI1_MOSI
PA8.Signal=S_TIM1_CH1
PB0.Signal=GPIO_Output
PB10.Signal=USART3_TX
PB11.Signal=USART3_RX
PB12.Signal=GPIO_Output
PB13.Signal=GPIO_Output
PB14.Signal=GPIO_Output
PB15.Signal=GPIO_Output
PB5.Signal=GPXTI5
PB6.Signal=USART1_TX
PB7.Signal=USART1_RX
PB8.Signal=I2C1_SCL
PB9.Signal=I2C1_SDA
PC0.Signal=ADCx_IN10
PC1.Signal=ADCx_IN11
PC10.Signal=UART4_TX
PC11.Signal=UART4_RX
PC12.GPIO_Label=Optical Flow
PC12.Signal=UART5_TX
PC2.Signal=GPIO_Output
PC4.Signal=GPIO_Output
PC5.Signal=GPIO_Input
PC6.Signal=S_TIM8_CH1
PC7.Signal=S_TIM8_CH2
PC8.Signal=S_TIM8_CH3
PC9.Signal=S_TIM8_CH4
PD2.GPIO_Label=Optical Flow
PD2.Signal=UART5_RX
PH0-OSC_IN.Signal=RCC_OSC_IN
PH1-OSC_OUT.Signal=RCC_OSC_OUT

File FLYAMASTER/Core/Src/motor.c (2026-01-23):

/**
 * @file motor.c
 * @brief 电机控制实现
 * @version 1.0.0
 * @date 2026-01-18
 */

/* Includes ------------------------------------------------------------------*/
#include "motor.h"
#include "tim.h"

/* Exported variables --------------------------------------------------------*/
Motor_Output_t g_motor_output = {
    .pwm = {MOTOR_PWM_MIN, MOTOR_PWM_MIN, MOTOR_PWM_MIN, MOTOR_PWM_MIN},
    .ccr = {MOTOR_CCR_MIN, MOTOR_CCR_MIN, MOTOR_CCR_MIN, MOTOR_CCR_MIN},
    .throttle = 0.0f,
    .roll = 0.0f,
    .pitch = 0.0f,
    .yaw = 0.0f,
    .state = MOTOR_STATE_DISARMED,
    .airmode_enabled = false
};

/* Private functions ---------------------------------------------------------*/

/**
 * @brief 限幅函数
 */
uint16_t Motor_Constrain(int32_t value, uint16_t min, uint16_t max)
{
    if (value < (int32_t)min) return min;
    if (value > (int32_t)max) return max;
    return (uint16_t)value;
}

/**
 * @brief 将 PWM 值转换为 CCR 值
 */
uint16_t Motor_PWMtoCCR(uint16_t pwm)
{
    /* PWM 1000-2000us -> CCR 2000-4000 */
    /* CCR = PWM * 2 */
    return Motor_Constrain((int32_t)pwm * 2, MOTOR_CCR_MIN, MOTOR_CCR_MAX);
}

/* Exported functions --------------------------------------------------------*/

/**
 * @brief 初始化电机控制
 */
void Motor_Init(void)
{
    /* 设置初始 PWM 为最小值 */
    Motor_StopAll();
    
    /* 启动 TIM8 PWM 输出 */
    HAL_TIM_PWM_Start(&htim8, TIM_CHANNEL_1);
    HAL_TIM_PWM_Start(&htim8, TIM_CHANNEL_2);
    HAL_TIM_PWM_Start(&htim8, TIM_CHANNEL_3);
    HAL_TIM_PWM_Start(&htim8, TIM_CHANNEL_4);
    
    g_motor_output.state = MOTOR_STATE_DISARMED;
}

/**
 * @brief 解锁电机
 */
void Motor_Arm(void)
{
    if (g_motor_output.state == MOTOR_STATE_DISARMED) {
        g_motor_output.state = MOTOR_STATE_ARMED;
        
        /* 设置怠速 PWM */
        for (int i = 0; i < MOTOR_COUNT; i++) {
            g_motor_output.pwm[i] = MOTOR_PWM_IDLE;
            g_motor_output.ccr[i] = Motor_PWMtoCCR(MOTOR_PWM_IDLE);
        }
        
        Motor_ApplyOutput();
    }
}

/**
 * @brief 锁定电机
 */
void Motor_Disarm(void)
{
    g_motor_output.state = MOTOR_STATE_DISARMED;
    Motor_StopAll();
}

/**
 * @brief 检查电机是否解锁
 */
bool Motor_IsArmed(void)
{
    return (g_motor_output.state != MOTOR_STATE_DISARMED);
}

/**
 * @brief 设置单个电机 PWM
 */
void Motor_SetPWM(Motor_Index_t motor, uint16_t pwm)
{
    if (motor >= MOTOR_COUNT) return;
    
    pwm = Motor_Constrain(pwm, MOTOR_PWM_MIN, MOTOR_PWM_MAX);
    g_motor_output.pwm[motor] = pwm;
    g_motor_output.ccr[motor] = Motor_PWMtoCCR(pwm);
}

/**
 * @brief 设置所有电机 PWM
 */
void Motor_SetAllPWM(uint16_t pwm1, uint16_t pwm2, uint16_t pwm3, uint16_t pwm4)
{
    Motor_SetPWM(MOTOR_1, pwm1);
    Motor_SetPWM(MOTOR_2, pwm2);
    Motor_SetPWM(MOTOR_3, pwm3);
    Motor_SetPWM(MOTOR_4, pwm4);
}

/**
 * @brief 电机混控计算 (X 型机架)
 * 
 * 混控公式:
 * M1 (右前, CCW): Throttle - Roll - Pitch - Yaw
 * M2 (左后, CCW): Throttle + Roll + Pitch - Yaw
 * M3 (左前, CW):  Throttle + Roll - Pitch + Yaw
 * M4 (右后, CW):  Throttle - Roll + Pitch + Yaw
 */
void Motor_Mix(float throttle, float roll, float pitch, float yaw)
{
    if (g_motor_output.state == MOTOR_STATE_DISARMED) {
        Motor_StopAll();
        return;
    }
    
    g_motor_output.state = MOTOR_STATE_RUNNING;
    g_motor_output.throttle = throttle;
    g_motor_output.roll = roll;
    g_motor_output.pitch = pitch;
    g_motor_output.yaw = yaw;
    
    /* 油门映射: 0.0-1.0 -> 1000-2000 */
    float throttle_pwm = MOTOR_PWM_MIN + throttle * (MOTOR_PWM_MAX - MOTOR_PWM_MIN);
    
    /* 混控计算 */
    float motor_out[MOTOR_COUNT];
    motor_out[MOTOR_1] = throttle_pwm - roll - pitch - yaw;  /* 右前 CCW */
    motor_out[MOTOR_2] = throttle_pwm + roll + pitch - yaw;  /* 左后 CCW */
    motor_out[MOTOR_3] = throttle_pwm + roll - pitch + yaw;  /* 左前 CW */
    motor_out[MOTOR_4] = throttle_pwm - roll + pitch + yaw;  /* 右后 CW */
    
    /* Airmode 处理 */
    if (g_motor_output.airmode_enabled) {
        /* 找出最大和最小值 */
        float max_out = motor_out[0];
        float min_out = motor_out[0];
        for (int i = 1; i < MOTOR_COUNT; i++) {
            if (motor_out[i] > max_out) max_out = motor_out[i];
            if (motor_out[i] < min_out) min_out = motor_out[i];
        }
        
        /* 计算需要的偏移量 */
        float offset = 0.0f;
        if (max_out > MOTOR_PWM_MAX) {
            offset = MOTOR_PWM_MAX - max_out;
        } else if (min_out < MOTOR_PWM_IDLE) {
            offset = MOTOR_PWM_IDLE - min_out;
        }
        
        /* 应用偏移 */
        for (int i = 0; i < MOTOR_COUNT; i++) {
            motor_out[i] += offset;
        }
    }
    
    /* 限幅并设置 PWM */
    for (int i = 0; i < MOTOR_COUNT; i++) {
        uint16_t pwm;
        if (throttle < 0.05f && !g_motor_output.airmode_enabled) {
            /* 低油门时使用怠速 */
            pwm = MOTOR_PWM_IDLE;
        } else {
            pwm = Motor_Constrain((int32_t)motor_out[i], MOTOR_PWM_IDLE, MOTOR_PWM_MAX);
        }
        g_motor_output.pwm[i] = pwm;
        g_motor_output.ccr[i] = Motor_PWMtoCCR(pwm);
    }
}

/**
 * @brief 应用电机输出
 */
void Motor_ApplyOutput(void)
{
    if (g_motor_output.state == MOTOR_STATE_DISARMED) {
        /* 锁定状态，输出最小值 */
        __HAL_TIM_SET_COMPARE(&htim8, TIM_CHANNEL_1, MOTOR_CCR_MIN);
        __HAL_TIM_SET_COMPARE(&htim8, TIM_CHANNEL_2, MOTOR_CCR_MIN);
        __HAL_TIM_SET_COMPARE(&htim8, TIM_CHANNEL_3, MOTOR_CCR_MIN);
        __HAL_TIM_SET_COMPARE(&htim8, TIM_CHANNEL_4, MOTOR_CCR_MIN);
    } else {
        /* 输出混控结果 */
        __HAL_TIM_SET_COMPARE(&htim8, TIM_CHANNEL_1, g_motor_output.ccr[MOTOR_1]);
        __HAL_TIM_SET_COMPARE(&htim8, TIM_CHANNEL_2, g_motor_output.ccr[MOTOR_2]);
        __HAL_TIM_SET_COMPARE(&htim8, TIM_CHANNEL_3, g_motor_output.ccr[MOTOR_3]);
        __HAL_TIM_SET_COMPARE(&htim8, TIM_CHANNEL_4, g_motor_output.ccr[MOTOR_4]);
    }
}

/**
 * @brief 停止所有电机
 */
void Motor_StopAll(void)
{
    for (int i = 0; i < MOTOR_COUNT; i++) {
        g_motor_output.pwm[i] = MOTOR_PWM_MIN;
        g_motor_output.ccr[i] = MOTOR_CCR_MIN;
    }
    
    __HAL_TIM_SET_COMPARE(&htim8, TIM_CHANNEL_1, MOTOR_CCR_MIN);
    __HAL_TIM_SET_COMPARE(&htim8, TIM_CHANNEL_2, MOTOR_CCR_MIN);
    __HAL_TIM_SET_COMPARE(&htim8, TIM_CHANNEL_3, MOTOR_CCR_MIN);
    __HAL_TIM_SET_COMPARE(&htim8, TIM_CHANNEL_4, MOTOR_CCR_MIN);
}

/**
 * @brief 使能/禁用 Airmode
 */
void Motor_SetAirmode(bool enable)
{
    g_motor_output.airmode_enabled = enable;
}

/**
 * @brief 获取电机 PWM 值
 */
uint16_t Motor_GetPWM(Motor_Index_t motor)
{
    if (motor >= MOTOR_COUNT) return MOTOR_PWM_MIN;
    return g_motor_output.pwm[motor];
}

/* 电机测试状态机变量 */
static struct {
    bool active;                /**< 测试是否激活 */
    Motor_Index_t motor;        /**< 当前测试的电机 */
    uint32_t start_time;        /**< 测试开始时间 */
    uint32_t duration_ms;       /**< 测试持续时间 */
    Motor_State_t prev_state;   /**< 测试前的电机状态 */
} s_motor_test = {0};
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

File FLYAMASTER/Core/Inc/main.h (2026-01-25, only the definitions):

#define Power_Key_Pin GPIO_PIN_0
#define Power_Key_GPIO_Port GPIOA
#define FLASH_CS_Pin GPIO_PIN_4
#define FLASH_CS_GPIO_Port GPIOA
#define Optical_Flow_Pin GPIO_PIN_12
#define Optical_Flow_GPIO_Port GPIOC
#define Optical_FlowD2_Pin GPIO_PIN_2
#define Optical_FlowD2_GPIO_Port GPIOD
#define OSD_CS_Pin GPIO_PIN_4
#define OSD_CS_GPIO_Port GPIOC
#define LED_BLUE_Pin GPIO_PIN_3
#define LED_BLUE_GPIO_Port GPIOC
#define LED_RED_Pin GPIO_PIN_4
#define LED_RED_GPIO_Port GPIOC
#define BUZZER_Pin GPIO_PIN_2
#define BUZZER_GPIO_Port GPIOC
#define PWR_HOLD_Pin GPIO_PIN_1
#define PWR_HOLD_GPIO_Port GPIOC

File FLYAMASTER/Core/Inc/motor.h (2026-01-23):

/**
 * @file motor.h
 * @brief 电机控制模块 (PWM 输出 + 混控)
 * @version 1.0.0
 * @date 2026-01-18
 * 
 * @details
 * 实现四轴飞行器电机控制：
 * 1. TIM8 CH1-CH4 输出 400Hz PWM
 * 2. X 型机架混控算法
 * 3. Airmode 支持
 * 
 * 电机布局 (X 型机架，从上方看):
 *        前
 *    M3     M1
 *      \   /
 *       \ /
 *       / \
 *      /   \
 *    M2     M4
 *        后
 * 
 * M1 (右前): CCW (逆时针)
 * M2 (左后): CCW (逆时针)
 * M3 (左前): CW  (顺时针)
 * M4 (右后): CW  (顺时针)
 */

#ifndef __MOTOR_H
#define __MOTOR_H

#ifdef __cplusplus
extern "C" {
#endif

/* Includes ------------------------------------------------------------------*/
#include "main.h"
#include <stdint.h>
#include <stdbool.h>

/* Exported defines ----------------------------------------------------------*/

/* 电机数量 */
#define MOTOR_COUNT             4

/* PWM 参数 */
#define MOTOR_PWM_MIN           1000    /**< 最小 PWM 值 (电机停转) */
#define MOTOR_PWM_MAX           2000    /**< 最大 PWM 值 (全油门) */
#define MOTOR_PWM_IDLE          1100    /**< 怠速 PWM 值 */
#define MOTOR_PWM_ARM           1050    /**< 解锁时的最小 PWM */

/* TIM8 ARR = 4999, 对应 2MHz 计数时钟 */
/* PWM 占空比 = CCR / (ARR + 1) */
/* 1000us = 1000 * 2 = 2000 计数 */
/* 2000us = 2000 * 2 = 4000 计数 */
#define MOTOR_CCR_MIN           2000    /**< 最小 CCR 值 */
#define MOTOR_CCR_MAX           4000    /**< 最大 CCR 值 */
#define MOTOR_CCR_IDLE          2200    /**< 怠速 CCR 值 */

/* 混控限制 */
#define MOTOR_MIX_LIMIT         500.0f  /**< 混控输出限幅 */

/* Exported types ------------------------------------------------------------*/

/**
 * @brief 电机索引枚举
 */
typedef enum {
    MOTOR_1 = 0,    /**< 右前 (CCW) - PC6 TIM8_CH1 */
    MOTOR_2,        /**< 左后 (CCW) - PC7 TIM8_CH2 */
    MOTOR_3,        /**< 左前 (CW)  - PC8 TIM8_CH3 */
    MOTOR_4         /**< 右后 (CW)  - PC9 TIM8_CH4 */
} Motor_Index_t;

/**
 * @brief 电机状态枚举
 */
typedef enum {
    MOTOR_STATE_DISARMED = 0,   /**< 锁定状态 */
    MOTOR_STATE_ARMED,          /**< 解锁状态 */
    MOTOR_STATE_RUNNING         /**< 运行状态 */
} Motor_State_t;

/**
 * @brief 电机输出结构体
 */
typedef struct {
    uint16_t pwm[MOTOR_COUNT];      /**< PWM 值 (1000-2000) */
    uint16_t ccr[MOTOR_COUNT];      /**< CCR 值 (直接写入寄存器) */
    float throttle;                 /**< 油门输入 (0.0-1.0) */
    float roll;                     /**< 横滚输入 */
    float pitch;                    /**< 俯仰输入 */
    float yaw;                      /**< 偏航输入 */
    Motor_State_t state;            /**< 电机状态 */
    bool airmode_enabled;           /**< Airmode 使能 */
} Motor_Output_t;

/* Exported variables --------------------------------------------------------*/
extern Motor_Output_t g_motor_output;   /**< 全局电机输出 */

/* Exported functions --------------------------------------------------------*/

/**
 * @brief 初始化电机控制
 * @note 启动 TIM8 PWM 输出
 */
void Motor_Init(void);

/**
 * @brief 解锁电机
 * @note 电机开始输出怠速 PWM
 */
void Motor_Arm(void);

/**
 * @brief 锁定电机
 * @note 电机停止输出
 */
void Motor_Disarm(void);

/**
 * @brief 检查电机是否解锁
 * @return bool true=已解锁, false=已锁定
 */
bool Motor_IsArmed(void);

/**
 * @brief 设置单个电机 PWM
 * @param motor 电机索引
 * @param pwm PWM 值 (1000-2000)
 */
void Motor_SetPWM(Motor_Index_t motor, uint16_t pwm);

/**
 * @brief 设置所有电机 PWM
 * @param pwm1 电机 1 PWM
 * @param pwm2 电机 2 PWM
 * @param pwm3 电机 3 PWM
 * @param pwm4 电机 4 PWM
 */
void Motor_SetAllPWM(uint16_t pwm1, uint16_t pwm2, uint16_t pwm3, uint16_t pwm4);

/**
 * @brief 电机混控计算 (X 型机架)
 * @param throttle 油门 (0.0 - 1.0)
 * @param roll 横滚 PID 输出
 * @param pitch 俯仰 PID 输出
 * @param yaw 偏航 PID 输出
 */
void Motor_Mix(float throttle, float roll, float pitch, float yaw);

/**
 * @brief 应用电机输出
 * @note 将混控结果写入 PWM 寄存器
 */
void Motor_ApplyOutput(void);

/**
 * @brief 停止所有电机
 */
void Motor_StopAll(void);

/**
 * @brief 使能/禁用 Airmode
 * @param enable true=使能, false=禁用
 */
void Motor_SetAirmode(bool enable);

/**
 * @brief 获取电机 PWM 值
 * @param motor 电机索引
 * @return uint16_t PWM 值
 */
uint16_t Motor_GetPWM(Motor_Index_t motor);

/**
 * @brief 启动电机测试 (非阻塞)
 * @param motor 电机索引
 * @param duration_ms 持续时间 (ms)
 * @return bool true=启动成功, false=已有测试在进行
 */
bool Motor_TestStart(Motor_Index_t motor, uint32_t duration_ms);

/**
 * @brief 更新电机测试状态机 (非阻塞)
 * @note 需要在主循环或任务中周期性调用
 * @return bool true=测试仍在进行, false=测试已完成或未激活
 */
bool Motor_TestUpdate(void);

/**
 * @brief 检查电机测试是否正在进行
 * @return bool true=测试中, false=空闲
 */
bool Motor_IsTestActive(void);

/**
 * @brief 停止电机测试
 */
void Motor_TestStop(void);

/**
 * @brief 电机测试 (阻塞方式，仅用于非 RTOS 环境)
 * @param motor 电机索引
 * @param duration_ms 持续时间 (ms)
 * @deprecated 在 FreeRTOS 环境中请使用 Motor_TestStart() + Motor_TestUpdate()
 */
void Motor_Test(Motor_Index_t motor, uint32_t duration_ms);

/**
 * @brief 将 PWM 值转换为 CCR 值
 * @param pwm PWM 值 (1000-2000)
 * @return uint16_t CCR 值
 */
uint16_t Motor_PWMtoCCR(uint16_t pwm);

/**
 * @brief 限幅函数
 * @param value 输入值
 * @param min 最小值
 * @param max 最大值
 * @return uint16_t 限幅后的值
 */
uint16_t Motor_Constrain(int32_t value, uint16_t min, uint16_t max);

#ifdef __cplusplus
}
#endif

#endif /* __MOTOR_H */

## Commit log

2026-01-23 feat(hw): FLYAMASTER v2.4.0 硬件设计完成
    [4 IN 1.kicad_pcb, 4 IN 1.kicad_sch, Peon230_ArmSupport_v1.stl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]
2026-01-23 docs: 添加强版权声明 - 严格保留所有权利
2026-01-23 docs: 添加项目根目录 README.md (含原理图链接)
2026-01-23 docs: 添加多固件支持说明 (INAV/Betaflight/ArduPilot)
2026-01-23 docs: 更新贡献者信息
2026-01-23 docs: 添加 OSD 和 2S-9S 电调支持说明
2026-01-23 docs: 添加 PCB 渲染图 (正反面)
2026-01-23 docs: README 添加 PCB 渲染图展示
2026-01-23 docs: README 润色 - 添加项目由来、算法原理、问题解决、作者信息
2026-01-25 HW v2.5.7: SPI CS pin swap, PCB layout v1, CubeMX update
    [untitled.kicad_sch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]

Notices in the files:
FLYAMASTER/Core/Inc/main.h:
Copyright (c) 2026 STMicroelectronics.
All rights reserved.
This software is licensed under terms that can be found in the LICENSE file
